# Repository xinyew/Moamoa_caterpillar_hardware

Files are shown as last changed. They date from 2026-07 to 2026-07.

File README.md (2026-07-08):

# Caterpillar — Hardware

KiCad project for the **caterpillar** board: a custom nRF54L15-based motor-control + IMU
board (vibration robot). Firmware lives in a sibling repo:
`Moamoa_caterpillar_firmware` (Zephyr / nRF Connect SDK v3.3.0, board target
`caterpillar/nrf54l15/cpuapp`).

## Board overview

| Subsystem | IC | Interface | Purpose |
| --- | --- | --- | --- |
| MCU + BLE | Raytac AN54LQ-P15 (nRF54L15) | — | Application core + BLE remote control |
| Motor driver | DRV8212P | PWM + GPIO  | Dual-channel motor control |
| Digital pot  | MAX5419LETA | I2C`0x28` | Adjusts motor supply voltage via STBB1-APUR |
| Buck-boost | STBB1-APUR | GPIO enable | Motor supply rail |
| Buck-boost | ADP2503 (3.3 V) | — | Logic supply rail |
| IMU | ASM330LHHTR | SPI | 6-axis accel/gyro |
| Inductor | TDK VLCF4020T-2R2N1R7 | — | 2.2 µH power inductor |

## Pin map (must stay in sync with firmware)

| Signal | Pin | Dir | Notes |
| --- | ----- | ----- | --- |
| I2C SDA | P1.02 | bidir | Digipot only (`i2c20`) |
| I2C SCL | P1.03 | out | Digipot only |
| IMU INT1 | P1.04 | in | ASM330LHHTR data-ready |
| IMU INT2 | P1.05 | in | ASM330LHHTR secondary interrupt |
| SPI CS | P1.09 | out | ASM330LHHTR chip select, active-low |
| SPI SCLK | P1.10 | out | IMU SPI clock |
| SPI MOSI | P1.13 | out | IMU SPI data out (U2 SDI) |
| SPI MISO | P1.14 | in | IMU SPI data in (U2 SDO) |
| STATUS LED | P0.01 | out | Blue LED via 470R, active-high |
| DRV8212 ~SLEEP | P1.06 | out | Active-low sleep (LOW = sleep) |
| PWM IN1 | P1.07 | out | Motor driver channel 1 (`pwm20`)  |
| PWM IN2 | P1.08 | out | Motor driver channel 2 |
| DCDC EN | P2.03 | out | STBB1-APUR enable, active-high |

If you change any of these nets, update the devicetree in the firmware repo
(`boards/kamoamoa/caterpillar/`) and this table.

## Project files

```
caterpillar.kicad_pro   project settings
caterpillar.kicad_sch   schematic
caterpillar.kicad_pcb   PCB layout
caterpillar.csv         BOM export
sym-lib-table           project symbol libraries
fp-lib-table            project footprint libraries
library/                custom components (see rules below)
```

`caterpillar.kicad_prl` and `fp-info-cache` are per-user/cache files and are gitignored.

## Library component organization — the rules

Every custom component lives in its own folder under `library/`, laid out exactly like this:

```
library/<PART>/
  <PART>.kicad_sym          symbol library (named after the part, no dated filenames)
  footprints.pretty/        footprint library (one .kicad_mod per footprint variant)
  <model>.step              3D model (optional)
```

Conventions:

1. **Every footprint links its 3D model.** If the component has a STEP file,
   *each* `.kicad_mod` in `footprints.pretty/` (including -L/-M density variants)
   must contain a `(model ...)` clause pointing to it — otherwise the part renders
   as bare pads in the 3D viewer. Vendor downloads often ship the `.kicad_mod`
   without this clause; add it when importing.
2. **3D model paths are project-relative** — inside a footprint use
   `(model "library/<PART>/<model>.step")`, not `${KIPRJMOD}/...` and never an
   absolute path.
3. **The symbol's Footprint property** must be fully qualified:
   `<fp-lib-nickname>:<footprint-name>`, so placing the symbol auto-assigns
   the footprint.
4. **Register both tables** — add the `.kicad_sym` to `sym-lib-table` and the
   `footprints.pretty/` folder to `fp-lib-table`, both via `${KIPRJMOD}` URIs.
5. **Keep only what KiCad needs.** From vendor downloads (SamacSys/Mouser,
   UltraLibrarian, CSE) copy only the `.kicad_sym`, the `.kicad_mod`(s), and the
   STEP model. Do not commit legacy `.lib`/`.dcm`/`.mod` files, other-CAD folders,
   ImportGuides/readme junk, or the original .zip.

### Importing a new vendor component, step by step

1. `mkdir library/<PART>/footprints.pretty`
2. Copy `<vendor>.kicad_sym` → `library/<PART>/<PART>.kicad_sym`
3. Copy `*.kicad_mod` → `library/<PART>/footprints.pretty/`
4. Copy the `.step`/`.stp` → `library/<PART>/`
5. In the footprint(s), set the model path to `library/<PART>/<model>.step`
6. In the symbol, set the Footprint property to `<PART>:<footprint-name>`
7. Add one entry each to `sym-lib-table` and `fp-lib-table`
8. Verify in KiCad: symbol chooser shows the part, footprint 3D viewer shows the model

## Notes

- Fab history: boards to be ordered.

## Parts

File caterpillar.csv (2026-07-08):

Reference | Qty | Value | Footprint | MPN
C1,C2,C5,C6,C12,C13 | 6 | 100nF | Capacitor_SMD:C_0603_1608Metric
C3,C11 | 2 | 10uF | Capacitor_SMD:C_0603_1608Metric | GMC10X7R106K10NT
C8,C9 | 2 | 22uF | Capacitor_SMD:C_0603_1608Metric | CL10A226MP8NUNE
C10,C17 | 2 | 4.7uF | Capacitor_SMD:C_0603_1608Metric
D1 | 1 | LED_BLUE | LED_SMD:LED_0603_1608Metric | 150060BS75000
J1 | 1 | Conn_ARM_JTAG_SWD_10 | Connector_PinHeader_1.27mm:PinHeader_2x05_P1.27mm_Vertical_SMD | 4048
J2 | 1 | SM02B-SRSS-TB_LF__SN_ | SM02B-SRSS-TB:SM02BSRSSTBLFSN | SM02B-SRSS-TB
L1 | 1 | 4.7uH | Inductor_SMD:L_0603_1608Metric | MLZ1608M4R7WT000
L5 | 1 | 2.2uH | VLCF4020T-2R2N1R7:VLCF4020 | VLCF4020T-2R2N1R7
L6 | 1 | 1.5uH | Inductor_SMD:L_0603_1608Metric | LSCNB1608HKT1R5MD
M2 | 1 | AN54LQ-P15 | AN54LQ-P15:AN54LQ-P15 | AN54LQ-P15
R1 | 1 | 470 | Resistor_SMD:R_0603_1608Metric
R3,R8 | 2 | 4.7k | Resistor_SMD:R_0603_1608Metric
R4-R7 | 4 | 100k | Resistor_SMD:R_0603_1608Metric
R9 | 1 | 12.1k | Resistor_SMD:R_0603_1608Metric
U1 | 1 | STBB1-APUR | STBB1_APUR:SON_B1-APUR_STM-M | STBB1-APUR
U2 | 1 | ASM330LHHTR | ASM330LHHTR:LGA-14L_2P5X3X0P83_STM-L | ASM330LHHTR
U3 | 1 | DRV8212P | Package_SON:WSON-8-1EP_2x2mm_P0.5mm_EP0.9x1.6mm_ThermalVias | DRV8212P
U4 | 1 | ADP2503ACPZ-3.3-R7 | ADP2503ACPZ_3_3_R7:CP_10_9_ADI-M | ADP2503ACPZ-3.3-R7
U6 | 1 | max5419leta+T | max5419:21-0137_T833&plus_2_MXM-M | max5419leta+T

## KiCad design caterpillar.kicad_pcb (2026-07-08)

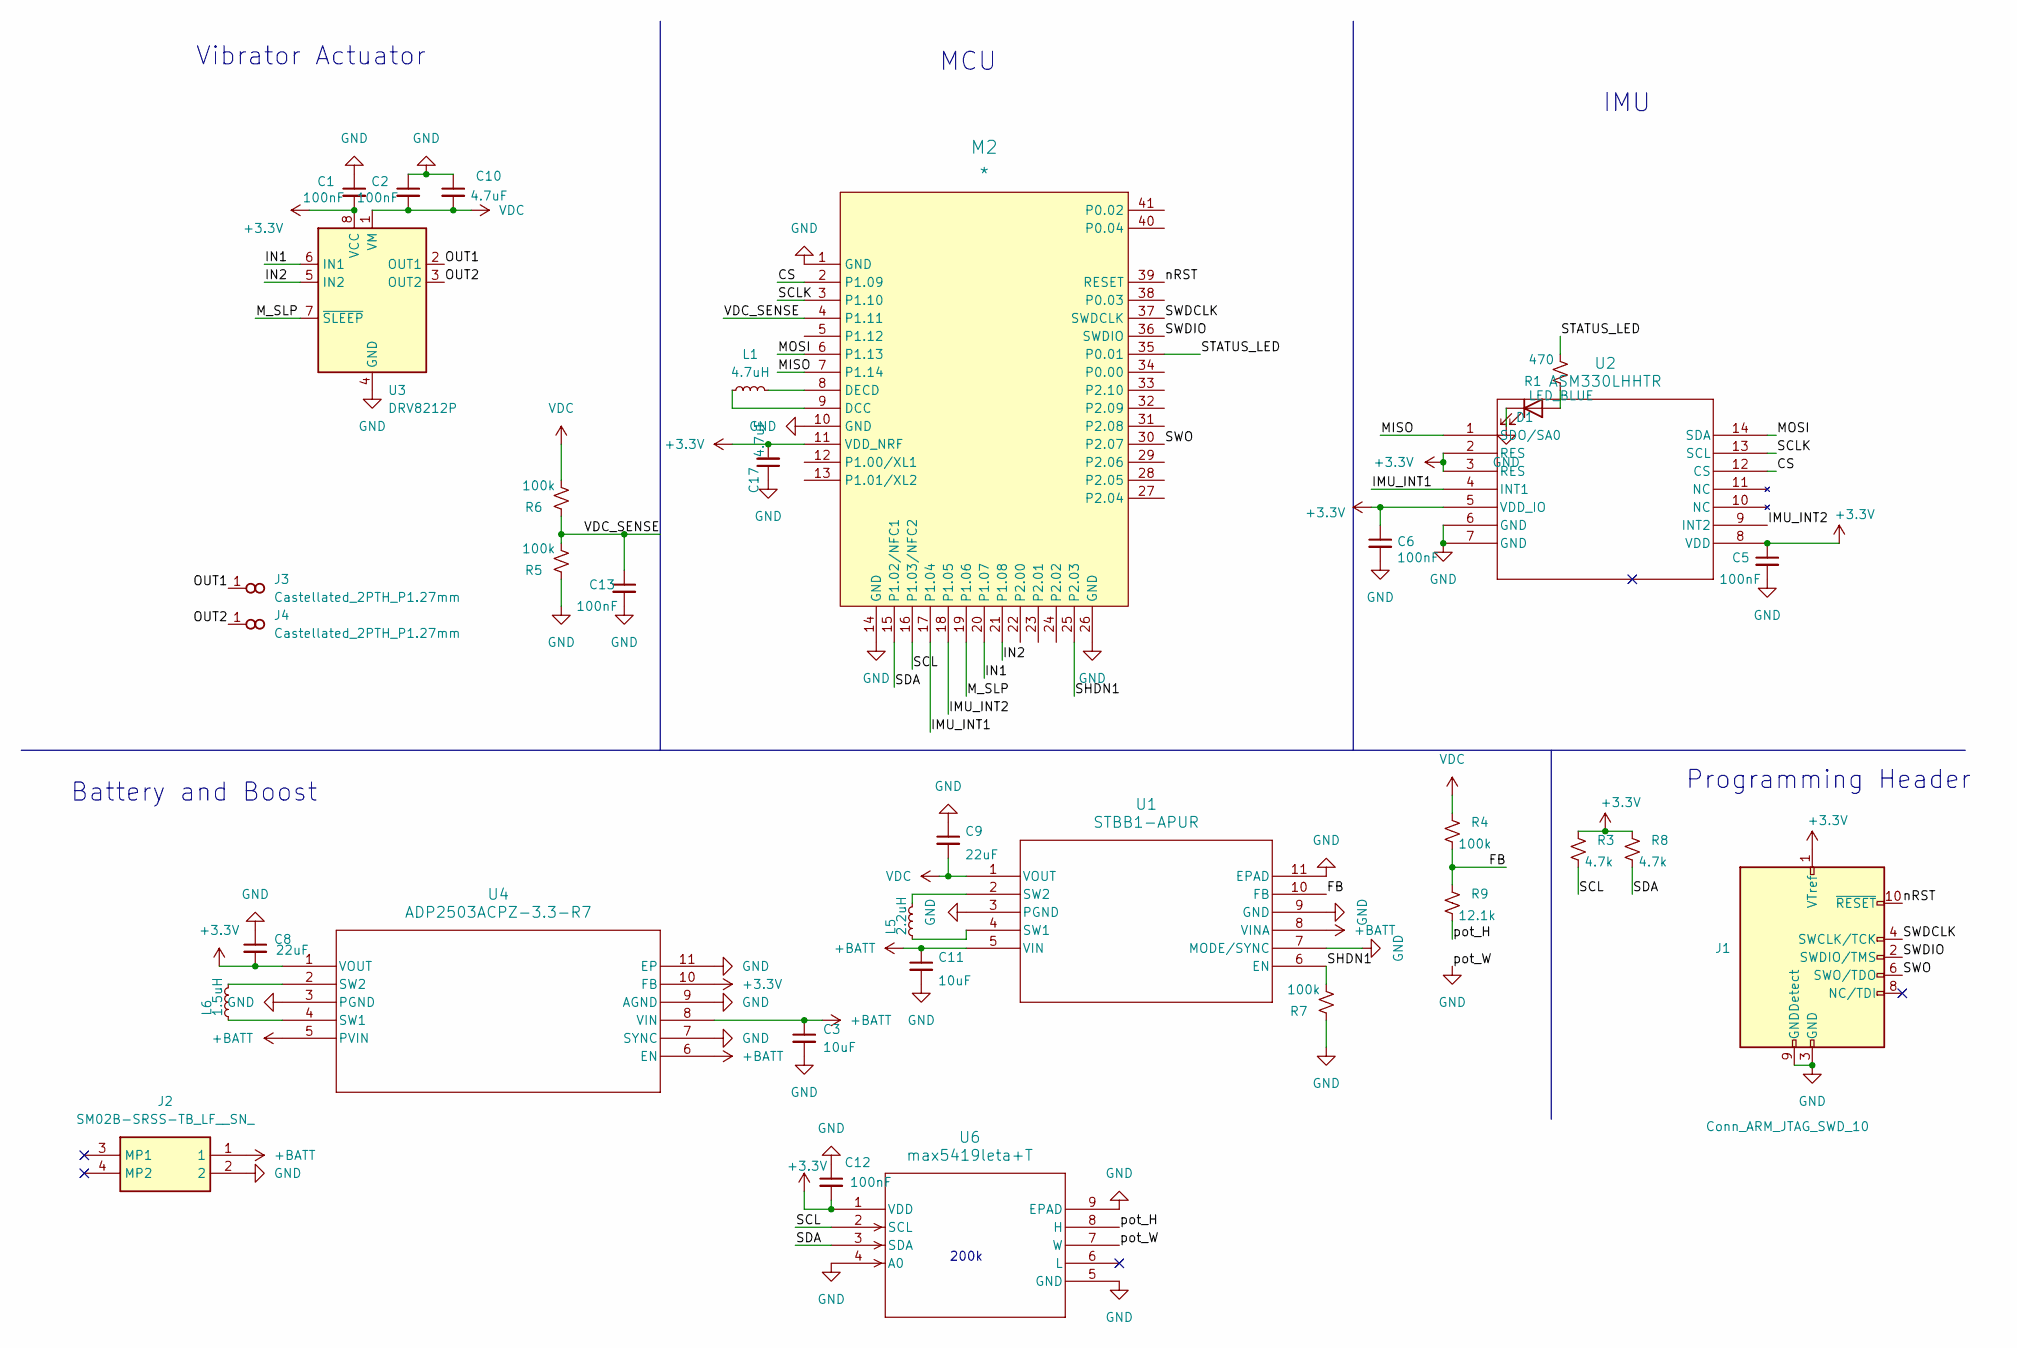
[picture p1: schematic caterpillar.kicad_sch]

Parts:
C1, C2, C5, C6, C12, C13: 100nF; C_0603_1608Metric
C3, C11: 10uF; C_0603_1608Metric; MPN GMC10X7R106K10NT
C8, C9: 22uF; C_0603_1608Metric; MPN CL10A226MP8NUNE
C10, C17: 4.7uF; C_0603_1608Metric
D1: LED_BLUE; LED_0603_1608Metric
J1: Conn_ARM_JTAG_SWD_10; PinHeader_2x05_P1.27mm_Vertical_SMD
J2: SM02B-SRSS-TB_LF__SN_; SM02BSRSSTBLFSN; Mouser Part Number N/A
J3, J4: Castellated_2PTH_P1.27mm
L1: 4.7uH; L_0603_1608Metric
L5: 2.2uH; VLCF4020
L6: 1.5uH; L_0603_1608Metric; MPN LSCNB1608HKT1R5MD
M2: *; AN54LQ-P15
R1: 470; R_0603_1608Metric
R3, R8: 4.7k; R_0603_1608Metric
R4, R5, R6, R7: 100k; R_0603_1608Metric
R9: 12.1k; R_0603_1608Metric
U1: STBB1-APUR; SON_B1-APUR_STM-M
U2: ASM330LHHTR; LGA-14L_2P5X3X0P83_STM-L
U3: DRV8212P; WSON-8-1EP_2x2mm_P0.5mm_EP0.9x1.6mm_ThermalVias
U4: ADP2503ACPZ-3.3-R7; CP_10_9_ADI-M
U6: max5419leta+T; 21-0137_T833&plus_2_MXM-M

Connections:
+3.3V: C1.2, C5.1, C6.1, C8.2, C12.2, C17.2, J1.1 (VTref), M2.11 (VDD_NRF), R3.1, R8.1, U2.2 (RES), U2.3 (RES), U2.5 (VDD_IO), U2.8 (VDD), U3.8 (VCC), U4.1 (VOUT), U4.10 (FB), U6.1 (VDD)
+BATT: C3.1, C11.1, J2.1, U1.5 (VIN), U1.8 (VINA), U4.5 (PVIN), U4.6 (EN), U4.8 (VIN)
/CS: M2.2 (P1.09), U2.12 (CS)
/FB: R4.2, R9.1, U1.10 (FB)
/IMU_INT1: M2.17 (P1.04), U2.4 (INT1)
/IMU_INT2: M2.18 (P1.05), U2.9 (INT2)
/IN1: M2.20 (P1.07), U3.6 (IN1)
/IN2: M2.21 (P1.08), U3.5 (IN2)
/MISO: M2.7 (P1.14), U2.1 (SDO/SA0)
/MOSI: M2.6 (P1.13), U2.14 (SDA)
/M_SLP: M2.19 (P1.06), U3.7 (~SLEEP)
/OUT1: J3.1 (~_1), U3.2 (OUT1)
/OUT2: J4.1 (~_1), U3.3 (OUT2)
/SCL: M2.16 (P1.03/NFC2), R3.2, U6.2 (SCL)
/SCLK: M2.3 (P1.10), U2.13 (SCL)
/SDA: M2.15 (P1.02/NFC1), R8.2, U6.3 (SDA)
/SHDN1: M2.25 (P2.03), R7.2, U1.6 (EN)
/STATUS_LED: M2.35 (P0.01), R1.2
/SWDCLK: J1.4 (SWCLK/TCK), M2.37 (SWDCLK)
/SWDIO: J1.2 (SWDIO/TMS), M2.36 (SWDIO)
/SWO: J1.6 (SWO/TDO), M2.30 (P2.07)
/VDC_SENSE: C13.1, M2.4 (P1.11), R5.2, R6.1
/nRST: J1.10 (~RESET), M2.39 (RESET)
/pot_H: R9.2, U6.8 (H)
GND: C1.1, C2.1, C3.2, C5.2, C6.2, C8.1, C9.1, C10.1, C11.2, C12.1, C13.2, C17.1, D1.1 (K), J1.3 (GND), J1.5 (GND), J1.9 (GNDDetect), J2.2, M2.1 (GND), M2.10 (GND), M2.14 (GND), M2.26 (GND), R5.1, R7.1, U1.3 (PGND), U1.7 (MODE/SYNC), U1.9 (GND), U1.11 (EPAD), U2.6 (GND), U2.7 (GND), U3.4 (GND), U3.9 (GND), U4.3 (PGND), U4.7 (SYNC), U4.9 (AGND), U4.11 (EP), U6.4 (A0), U6.5 (GND), U6.7 (W), U6.9 (EPAD)
unnamed: D1.2 (A), R1.1
unnamed: L1.1, M2.9 (DCC)
unnamed: L1.2, M2.8 (DECD)
unnamed: L5.1, U1.4 (SW1)
unnamed: L5.2, U1.2 (SW2)
unnamed: L6.1, U4.4 (SW1)
unnamed: L6.2, U4.2 (SW2)
VDC: C2.2, C9.2, C10.2, R4.1, R6.2, U1.1 (VOUT), U3.1 (VM)

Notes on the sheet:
Vibrator Actuator
MCU
IMU
Battery and Boost
Programming Header
200k

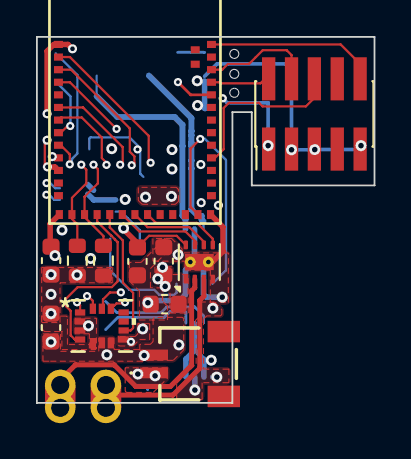
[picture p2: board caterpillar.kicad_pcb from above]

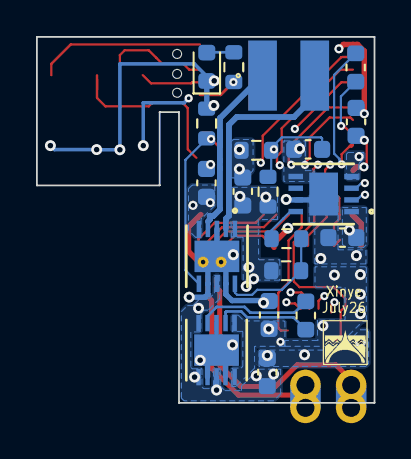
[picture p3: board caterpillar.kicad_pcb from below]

Board: 4 copper layers, 18.8 x 20.3 mm, 34 parts (20 on the bottom side), 33 nets.

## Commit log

2026-07-04 Initial commit: clean caterpillar KiCad project
    Cleaned up from the original messy vibropcbv2 folder:
    - Renamed project files vibropcbv2.* -> caterpillar.* (incl. internal
    sheetfile/project references)
    - Removed OS cruft, stale locks, KiCad auto-backups, old gerber/STEP
    exports, and already-extracted library download zips
    - Pruned library/ to only components used by the design: ADP2503
    buck-boost, ASM330LHH IMU, STBB1-APUR DC-DC, MAX5419 digipot
    - Repointed digipot footprint from redundant max5424 lib to max5419
    (identical TDFN-8 21-0137 footprint) and dropped the max5424 lib
    - Rewrote fp-lib-table/sym-lib-table to only resolving entries,
    removing the broken absolute AN54LQ-P15 pat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
    [caterpillar.csv, caterpillar.kicad_pcb, caterpillar.kicad_sch]
2026-07-04 library: restructure to flat per-part layout; add VLCF4020T inductor; add README
    - Add TDK VLCF4020T-2R2N1R7 2.2uH power inductor (symbol, footprint, STEP)
    from SamacSys download, keeping only the KiCad-native files
    - Flatten every component dir to a uniform layout:
    library/<PART>/{<PART>.kicad_sym, footprints.pretty/, <model>.step}
    (drop vendor KiCADv6/ nesting, dated symbol filenames, ImportGuides/readme)
    - Link 3D models in all footprints that have a STEP file, using
    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
    [caterpillar.kicad_pcb]
2026-07-04 library: extract AN54LQ-P15 module from design files into a real library
    The Raytac AN54LQ-P15 (nRF54L15) module existed only as embedded copies
    in the schematic/board; its source library was a broken absolute path
    on another machine. Extract it into library/AN54LQ-P15/ per the
    project's component layout:
    - footprint: pulled from the placed M2 via the pcbnew API (position
    reset, REF**, nets/sheet path stripped), 41 pads verified
    - symbol: extracted from the schematic's lib_symbols, wrapped as a
    KiCad 10 symbol library, Footprint property fully qualified
    - both lib tables gain an AN54LQ-P15 entry; nickname matches existing
    design references, so no design-file changes needed
    [caterpillar.kicad_sch]
2026-07-05 logos: extract kamoamoa into library; drop previous designer's mark
    - Extract the kamoamoa back-silkscreen logo from the board into
    library/Logos/footprints.pretty/ and register nickname "Logos",
    resolving the dangling Logos:kamoamoa reference
    - Remove the Kicad_library:Personal_small footprint (39-polygon
    personal mark of the original designer; its source library never
    existed on this machine)
    [caterpillar.kicad_pcb]
2026-07-05 library: add MAX5419 3D model, link in all footprint variants
    STEP model sourced by user; linked with project-relative path per
    library rules. Rotation (-90 X, 90 Z) tuned visually in KiCad on the
    -L variant and propagated to -M and base variants.
2026-07-05 library: add JST SM02B-SRSS-TB 2-pin SH connector
    Symbol/footprint from SamacSys (model path made project-relative,
    Footprint property qualified); 3D model replaced with higher-detail
    eec STEP. Registered in both lib tables as SM02B-SRSS-TB.
2026-07-05 replaced L5 with large inductor footprints. Fixed some warning about footprint links. Using M (largest pads) footprints for ICs now
    [caterpillar.kicad_sch]
2026-07-05 replaced all 0402 footprints with 0603
    [caterpillar.kicad_sch]
2026-07-05 library: add Castellated_2PTH_P1.27mm joined dual-hole solder point
    Two 2.54mm-header-style PTH (1.7mm pad, 1.0mm drill) at 1.27mm pitch,
    bridged by copper rect pads on front and back between the pad
    outlines; all pads share number 1. Single-pin symbol, excluded from
    BOM/position files. Note: 0.27mm drill-to-drill web -- confirm with fab.
    [caterpillar.kicad_pcb]
2026-07-05 pcb: remove orphaned duplicate C8 (4.7uF 0402)
    A manually-placed 3.3V decoupling cap with no schematic symbol shared
    the C8 reference with the real 22uF cap. No tool flagged it: pcbnew
    does not enforce unique references, F8 does not delete unmatched
    footprints by default, and DRC schematic-parity is opt-in.
    Note: already-fabricated boards do have this cap fitted.
    [caterpillar.kicad_pcb]
2026-07-05 pcb: fix corrupted layer stackup to standard 1.6mm 2-layer
    Previous stackup had hand-entered junk: 0.523mm bottom solder mask
    (52x reality), 0.046mm copper, 0.406mm core, totaling 1.0338mm.
    Now standard: 1oz (0.035mm) copper, 1.51mm FR4 core, 0.01mm masks,
    1.6mm total; general.thickness updated to match. Note: previously
    fabbed boards were ordered against the old numbers.
    [caterpillar.kicad_pcb]
2026-07-05 rules: import design rules from Altium project ruleset
    From altium_rules.RUL (36 rules, the importable subset):
    - constraints: min track 4mil, min hole 4mil, hole-to-hole 9.75mil,
    copper-to-edge 10mil (was 0/disabled), min via dia 9mil
    - solder mask expansion 4mil (was 0)
    - new Power net class (12mil tracks) assigned to +3.3V/+BATT/VDC/GND
    - caterpillar.kicad_dru: BLE_FEEDLINE scoped clearance (dormant until
    that class exists; its Altium width rule deliberately NOT imported -
    impedance-tuned to a different stackup) and 4mil courtyard clearance
    - Default net class track width 0.2 -> 0.1524mm (6mil, user choice)
    - remove stale radial dimension annotation on User.1
    Altium autorouter rules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
    [caterpillar.kicad_pcb]
2026-07-06 reorganized design a lot for better space organization
    [caterpillar.kicad_pcb, caterpillar.kicad_sch]
2026-07-06 component position&orientation adjusted further.
    [caterpillar.kicad_pcb]
2026-07-06 sch: move IMU to dedicated SPI; I2C stays for digipot; decoupling fixes
    - ASM330LHHTR now on SPI: CS=P1.09, SCLK=P1.10, MOSI=P1.13, MISO=P1.14
    (SDO/SA0 repurposed from I2C address strap to MISO)
    - I2C bus (P1.02/P1.03 + pull-ups) retained for MAX5419 digipot only
    - C6 repurposed 10uF -> 100nF as the IMU VDD_IO ceramic that the
    datasheet requires; bulk duty covered by C8 22uF, 3.2mm away
    - ADP2503 SYNC pin grounded (was floating) -> auto power-save mode
    - README pin map updated to match
    Firmware devicetree (boards/kamoamoa/caterpillar/) still describes the
    IMU on I2C - must be updated to SPI with these pins before next flash.
    [caterpillar.kicad_pcb, caterpillar.kicad_sch]
2026-07-06 sch: add VDC sense divider on P1.11; ground STBB1 MODE/SYNC; tidy power drawing
    - VDC telemetry: 100k/100k divider (/2) + 100nF filter (32Hz) into
    P1.11 SAADC; measures the digipot-set motor rail, ~22uA drain,
    quasi-static readings only by design (wait ~25ms after setpoint
    changes). Verify P1.11 is an AIN pin before fab.
    - STBB1 MODE/SYNC grounded (was floating) -> auto power-save, matches
    ADP2503 SYNC treatment
    - C3 redrawn at ADP2503 VIN for clarity (electrically unchanged);
    redundant +BATT symbol replaced with wires
    PENDING on the board: run Update PCB from Schematic WITH the
    "re-link by reference designator" option (repairs C3/C6 uuid links
    broken by delete-and-redraw) and pla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
    [caterpillar.kicad_sch]
2026-07-06 sch: motor-rail safety nets - EN pulldown, hardware VDC ceiling; drop C7
    - R7 100k pulldown on STBB1 EN (/SHDN1): rail guaranteed off while
    the MCU is in reset/bootloader/flashing (GPIO hi-Z)
    - R9 12.1k in series between MAX5419 H terminal and STBB1 FB:
    hardware VDC ceiling = 0.5*(1+100k/12.1k) ~= 4.63V regardless of
    firmware/BLE commands; max commandable ~4.3-4.5V (wiper R dependent)
    - C7 15pF feedforward cap removed (owner decision): STBB1 eval board
    ships without one, and R9 now floors the FB bottom leg at high
    frequency, damping the digipot-parasitic pole C7 likely compensated.
    Verify with a scope on VDC (digipot sweep + motor start) on first
    new build.
    Firmware ripple: di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
    [caterpillar.kicad_sch]
2026-07-06 pcb: sync with rev-2 schematic; bom: regenerate with MPN fields
    - Board updated from schematic (re-linked by reference): C3/C6 uuid
    links repaired, orphan C7 footprint removed, R7/R9/C13/R5/R6 placed
    onto the board (placement/routing to follow)
    - BOM regenerated from the current schematic (old caterpillar.csv was
    a stale Muscle_PCB-era export); grouped by value+footprint
    - MPN stored as symbol fields in the schematic so BOM exports carry
    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
    [caterpillar.csv, caterpillar.kicad_pcb, caterpillar.kicad_sch]
2026-07-07 zones created, power layer set up well that VDC, 3V3, and BATT grouped together by planes, GND layer added. Decoupling Caps position checked
    [caterpillar.kicad_pcb]
2026-07-07 all nets conencted
    [caterpillar.kicad_pcb]
2026-07-07 refilled. All nets connected, no schematic parity issues
    [caterpillar.kicad_pcb]
2026-07-07 all electrical issues fixed. Add as many vias as possible. connected nets on the same layer with polygon fills as much as possible. vias roughly realigned so looks much better
    [caterpillar.kicad_pcb]
2026-07-07 thickened the power tracks of motor driver, added more vias for VDC output, moved VDC_sense away from the SW2
    [caterpillar.kicad_pcb]
2026-07-07 pcb: shorten SPI runs inside the In2 GND plane by ~40%
    Inner-layer signal routing reduced 65.4mm -> 45.2mm (CS 15.9->9.4,
    SCLK 14.3->8.2, MOSI 12.9->8.6, MISO 12.5->8.9mm), shrinking the
    slots cut through the GND plane. Remaining in-plane routing is a
    recorded conscious-accept (slow SPI, short runs, board full on both
    outer layers); to be validated at first article via IMU noise floor
    with motor running + BLE RSSI A/B.
    [caterpillar.kicad_pcb]
2026-07-08 pcb: fix via-in-pad and hole-spacing DFM findings (scripted, DRC-verified)
    - deleted middle +BATT via of the triple at J2 (fixed both <0.25mm
    hole pairs there at once) plus its leftover stub
    - U2 pad 5 (LGA, un-reworkable under package): 0.2mm via pulled out
    of the pad, reconnected with a 0.15mm stub
    - VDC pair at C10: via repositioned within the same-net pad, all
    three VDC vias now >0.25mm hole-to-hole
    - U4 EP: third thermal via deleted instead of relocated (no legal
    spot between OUT1/OUT2 and the J2 mounting pad; 2 vias ample for
    the light-load 3.3V converter)
    - kept: J2 battery-pad vias (no legal landing site in that density;
    mitigate with flux/extra solder at assembly) and 06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
    [caterpillar.kicad_pcb]
2026-07-08 drc: edge clearance 0.2mm (PCBWay routed min) + by-design edge-copper rule
    - min_copper_edge_clearance 0.254 -> 0.2mm: legitimizes M2 module pads
    (0.22mm) and L5 pads (0.20mm), both within PCBWay standard capability
    - new dru rule 'edge_copper_by_design': edge_clearance min -1mm scoped
    to J3/J4 (castellations must cross the edge; clearance is negative,
    not zero) and J2 (accepted mounting-pad overhang)
    - also: removed relocated U2.5 via + stub (owner edit); VDD_IO is fed
    by the F.Cu 3.3V pour + existing via 1mm away, GND pour stays whole
    DRC: copper_edge_clearance 14 -> 0; all critical categories remain 0.
    [caterpillar.kicad_pcb]
2026-07-08 removed one warning in terms of unconnected track
    [caterpillar.kicad_pcb]
2026-07-08 sch: add blue status LED on P0.01 (D1 + R1 470R, 0603)
    P0.01 (module pin 35) -> R1 470R -> D1 anode, cathode -> GND;
    active-high, ~0.7-0.9mA at blue Vf - fine for nRF standard drive.
    Symbols/footprints from KiCad official libs (Device:LED imported
    into lib_symbols, R reuses Device:R_Small_US; LED_0603/R_0603).
    Netlist-verified including LED polarity (first draft had A/K
    swapped by a cloned-template rotation - caught by netlist check).
    BOM regenerated; README pin map updated.
    Board side still pending: place D1/R1, route STATUS_LED (F8 first).
    [caterpillar.csv, caterpillar.kicad_sch]
2026-07-08 LED added. DRC check good
    [caterpillar.kicad_pcb]
2026-07-08 readme: IMU overview row says SPI (was stale I2C); pin map was already correct
2026-07-08 BOM upto date.
    [caterpillar.csv]
2026-07-08 snap-off finalized
    [caterpillar.kicad_pcb]
